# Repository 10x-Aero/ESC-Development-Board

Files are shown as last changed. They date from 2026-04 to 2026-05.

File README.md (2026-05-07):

https://github.com/user-attachments/assets/5f652ef7-dc9c-4700-bebd-08a81333550c

# ESC Development Board

A 6S AM32-compatible ESC built as a proof of concept for learning how to design an ESC from scratch. It gets a motor spinning — that's about the extent of what's guaranteed. Beyond that, expect rough edges.

The design is sloppy in places. If you spot schematic, layout, or component choices that actively work against basic ESC functionality, open an issue.

## Hardware

- **MCU:** STM32F051
- **Firmware:** AM32
- **Max cells:** 6S

<p align="center">
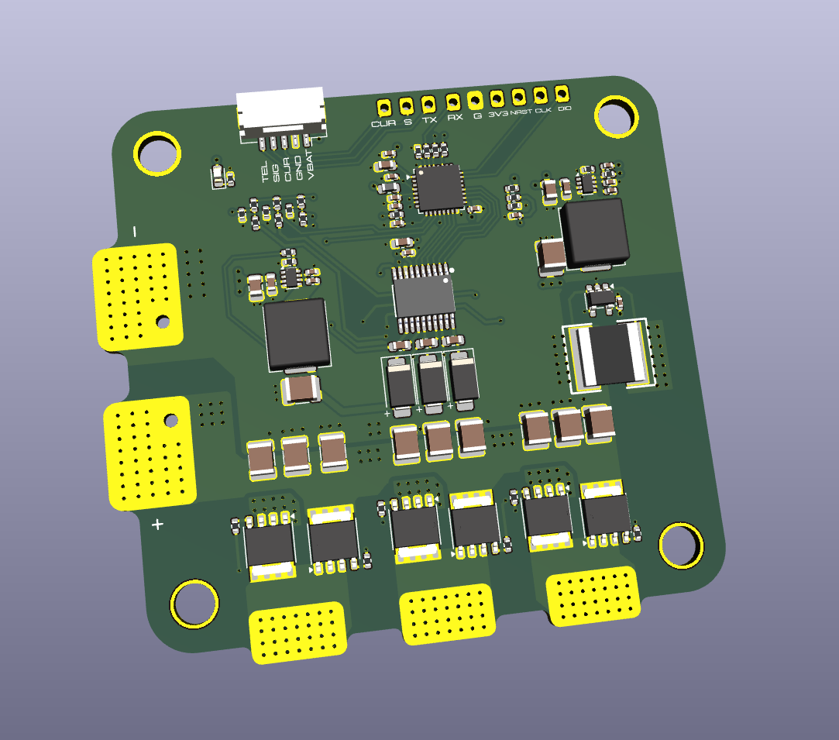
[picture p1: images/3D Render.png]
Front
  
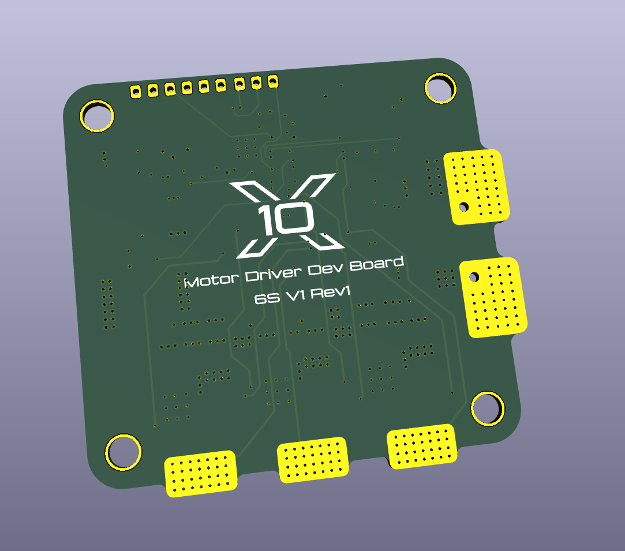
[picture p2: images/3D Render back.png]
Back
  
</p>

### Schematic

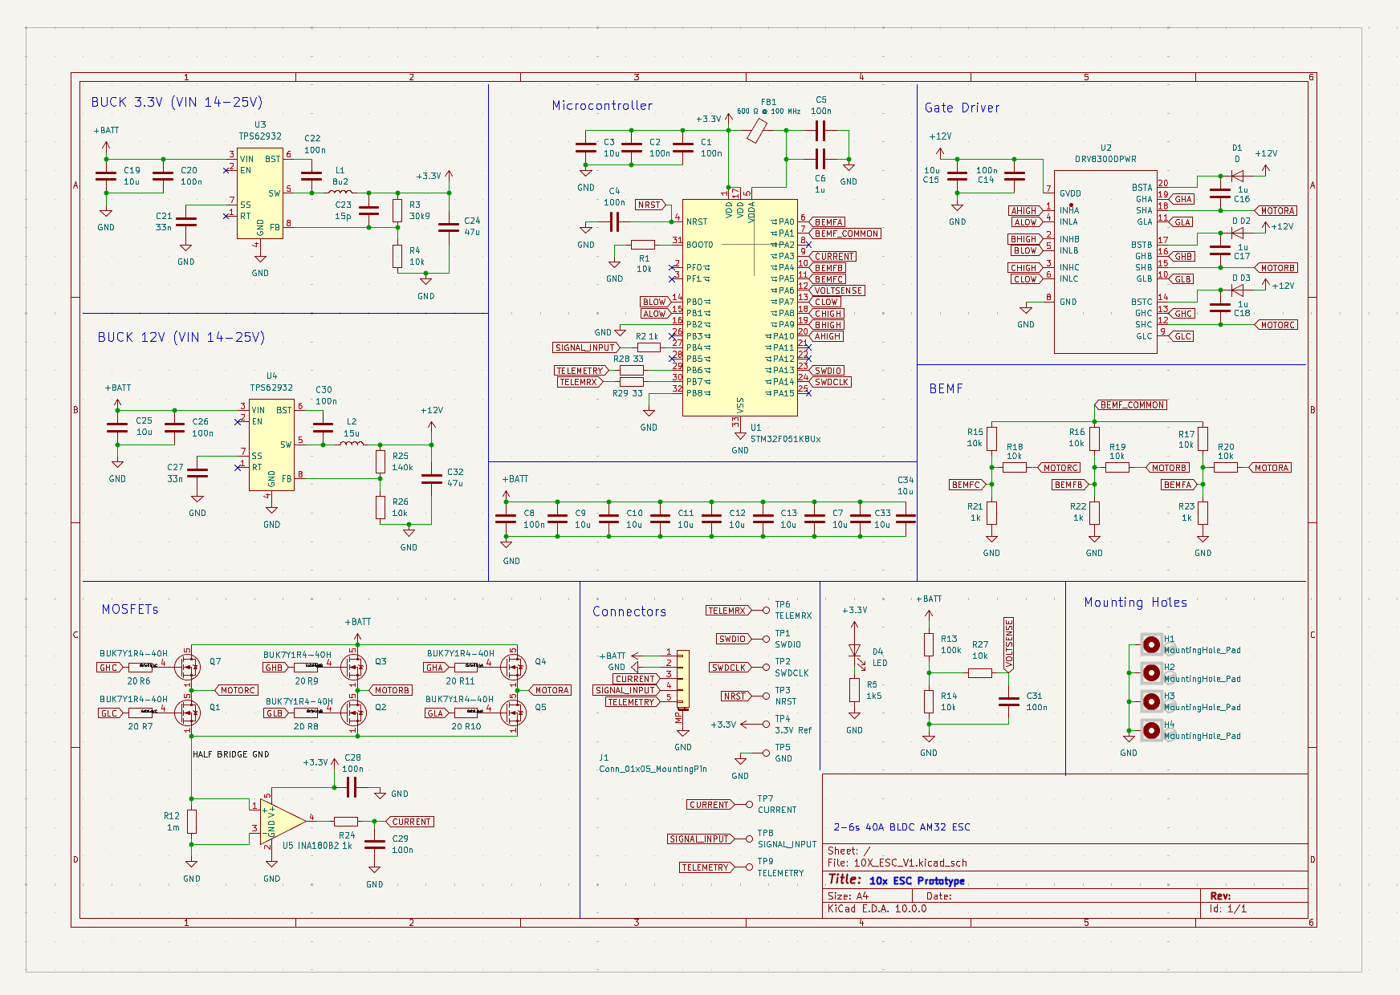
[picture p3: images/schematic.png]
Schematic


### PCB layers

<p align="center">
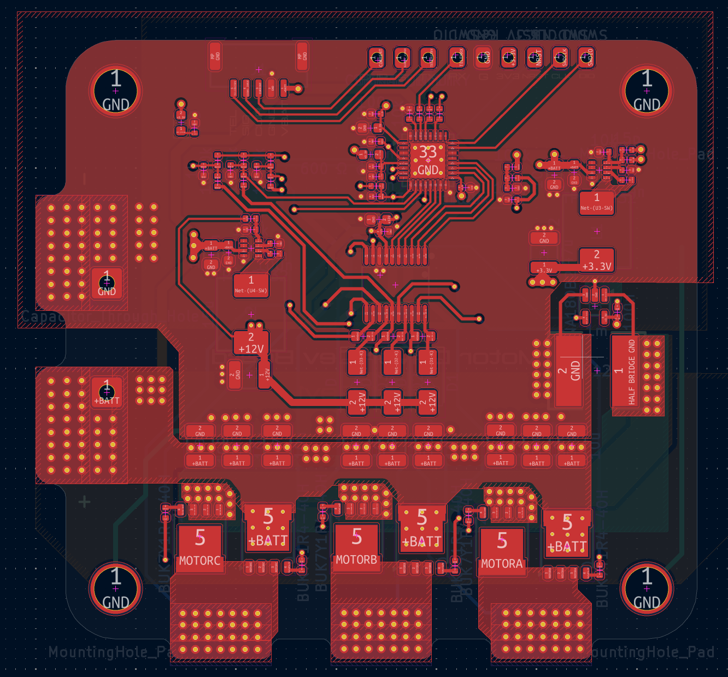
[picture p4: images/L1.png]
Layer 1 — Top
  
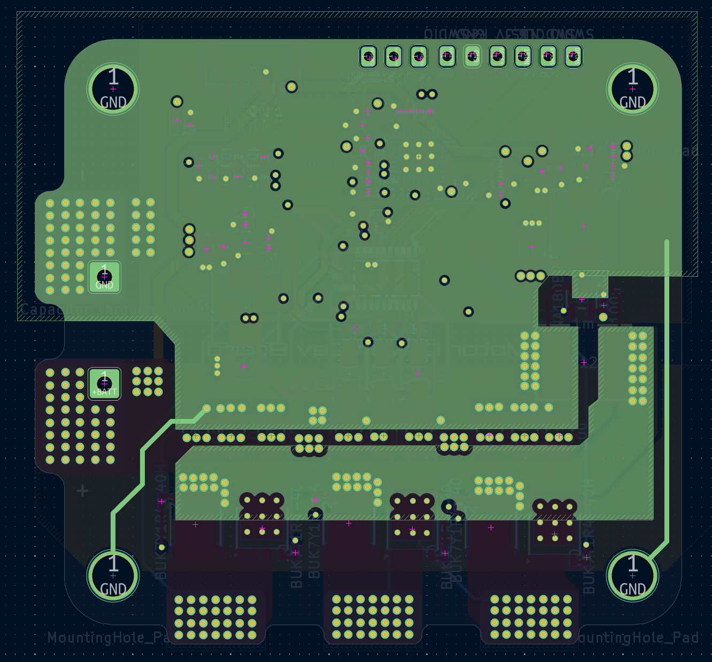
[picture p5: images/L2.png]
Layer 2
  
</p>
<p align="center">
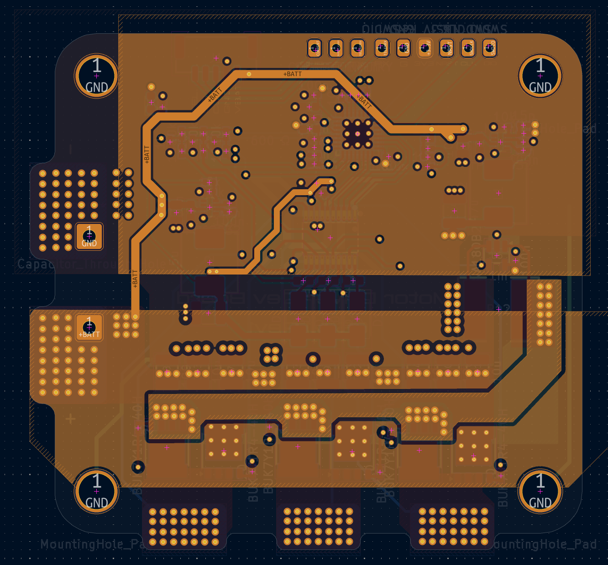
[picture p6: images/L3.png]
Layer 3
  
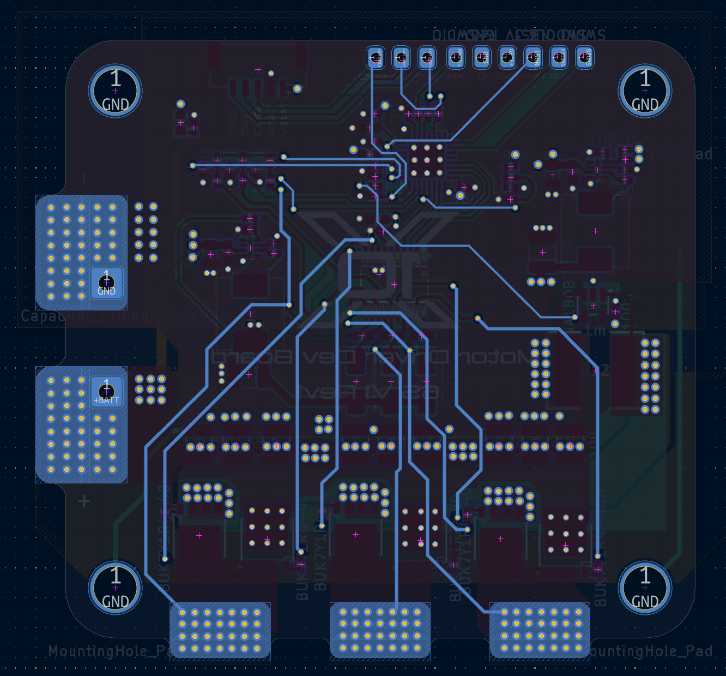
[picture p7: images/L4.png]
Layer 4 — Bottom
  
</p>

PCB

## Testing

### Setup

- **Motor:** AOS Supernova 3220 925KV
- **Battery:** 6S LiPo
- **Prop:** 7×7
- **Bulk cap:** 1000 µF
- **Measurement:** AC-coupled VBAT ripple, probed directly at the battery solder pads

### Throttle sequence

| t (s) | Action | Throttle | Duration |
| ----- | --- | --- | --- |
| 0.0 | Idle | — | 1.0 s |
| 1.0 | Ramp | 0 → 20%  | 1.5 s |
| 2.5 | Hold (capture) | 20% | 2.0 s |
| 4.5 | Ramp | 20 → 35% | 0.8 s |
| 5.3 | Hold (capture) | 35% | 2.0 s |
| 7.3 | Ramp | 35 → 50% | 0.8 s |
| 8.1 | Hold (capture) | 50% | 2.0 s |
| 10.1  | Ramp | 50 → 65% | 0.8 s |
| 10.9  | Hold (capture) | 65% | 2.0 s |
| 12.9  | Ramp | 65 → 80% | 0.8 s |
| 13.7  | Hold (capture) | 80% | 2.0 s |
| 15.7  | Ramp | 80 → 95% | 0.8 s |
| 16.5  | Hold (capture) | 95% | 2.0 s |
| 18.5  | Ramp down | 95 → 0%  | 1.5 s |
| 20.0  | End | — | — |

### Results

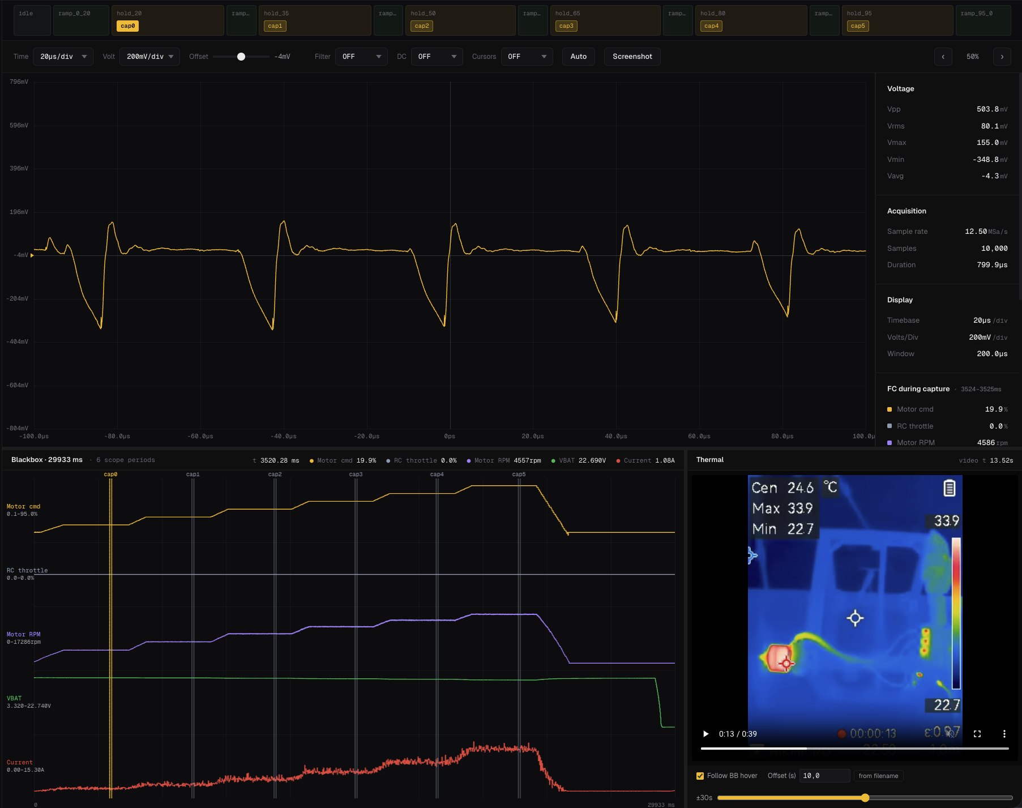
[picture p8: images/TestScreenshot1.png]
VBAT ripple — low throttle


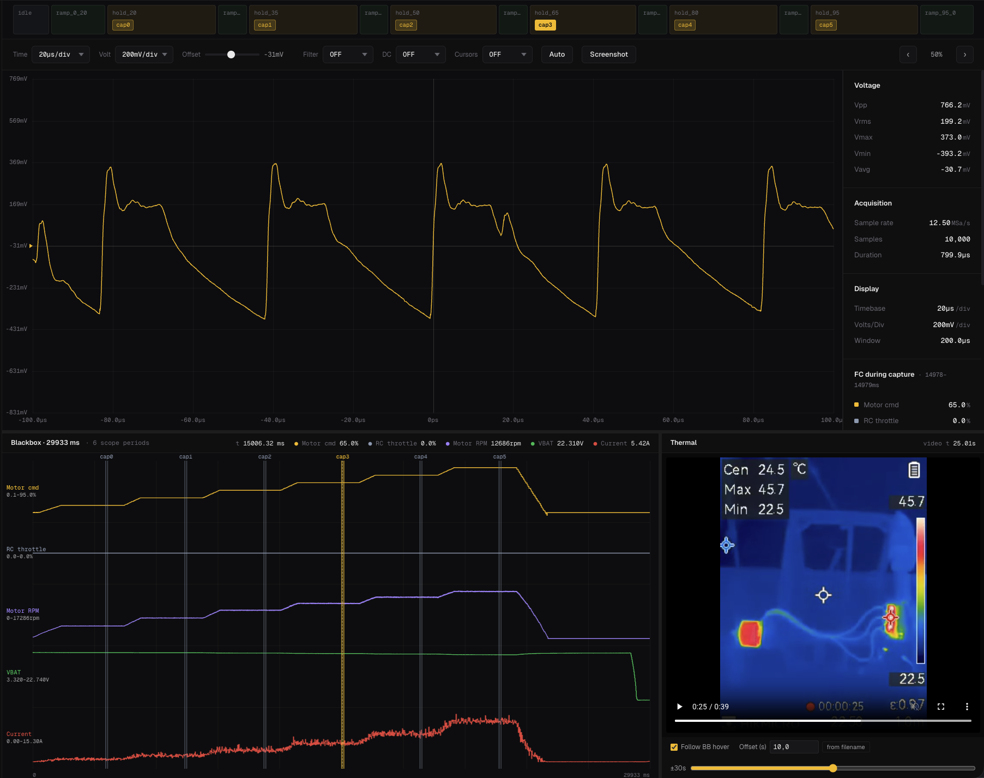
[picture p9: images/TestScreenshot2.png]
VBAT ripple — mid throttle


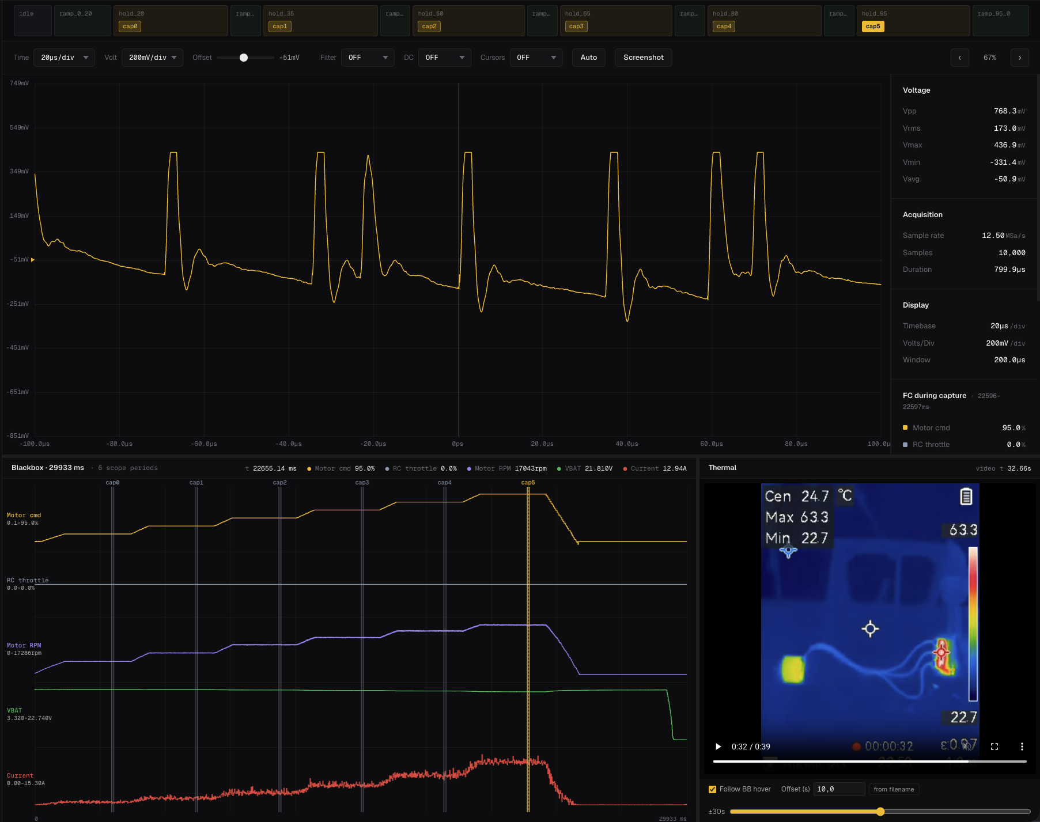
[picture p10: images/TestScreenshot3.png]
VBAT ripple — high throttle


https://github.com/user-attachments/assets/3ce99b9d-343a-43b4-ace9-065e4792fe87

## Known mistakes

- The DRV8300DPWR has internal bootstrap diodes, so the external bootstrap diodes on this design are redundant. Doesn't break anything — just unnecessary parts cost and board area.

## Flashing AM32 on a custom ESC

General workflow for getting AM32 running on any custom STM32-based ESC, not just this one. Two things to figure out for your own board: which AM32 target matches your pin layout, and how to physically flash it.

### Figuring out the pin config

AM32 organizes pin assignments in two layers:

- **Hardware groups** define the low-level pins — signal input, the six phase outputs (three high-side PWM + three low-side COM), BEMF feedback pins, and the comparator reference. Grouped per MCU family (`F0_A`, `F0_B`, etc.) and listed in the [AM32 Supported Hardware wiki](https://github.com/AlkaMotors/AM32-MultiRotor-ESC-firmware/wiki/List-of-Supported-Hardware).
- **Targets** sit on top of a hardware group and add ADC pins for voltage and current sensing, plus anything board-specific like LED pins. Target definitions live in `Inc/targets.h` in the [am32-firmware/AM32 repo](https://github.com/am32-firmware/AM32) as `#ifdef` blocks.

Compare your schematic against the hardware group table. If one matches your phase outputs, BEMF pins, and signal input exactly, use it and write a target that points to your ADC pins. If nothing matches, you'll need to define a new hardware group — that means editing the MCU-level source, not just a target header.

Match your signal input pin carefully. The bootloader `.hex` filename encodes which pin it expects (e.g. `..._PB4_V17.hex` expects the signal on PB4). Mismatches mean the ESC won't respond to the configurator.

### Flashing the bootloader

SWD only — the bootloader has to go on over ST-Link. Wire SWDIO, SWCLK, and GND from the ST-Link to the SWD pads on the ESC, and power the ESC from a LiPo.

1. Install [ST-LINK Utility](https://www.st.com/en/development-tools/stsw-link004.html).
2. Grab the correct bootloader from [am32.ca/downloads](https://am32.ca/downloads).
3. Flash the `.hex` to `0x08000000`.

### Flashing the firmware

Once the bootloader is on, the main firmware goes over the signal wire via FC passthrough — no more SWD needed.

1. Connect the ESC's signal and GND to a flight controller motor output, and plug the FC into your PC via USB.
2. Install the [AM32 Offline Configurator](https://github.com/am32-firmware/Offline-Configurator/releases).
3. Download the firmware `.hex` matching your target from the [AM32 releases](https://github.com/am32-firmware/AM32/releases).
4. Open the configurator, connect to the FC's serial port, and flash the `.hex`.

The FC needs to be running a DShot protocol (300 or 600) for passthrough to work, and the ESC needs battery power — USB alone won't boot it.

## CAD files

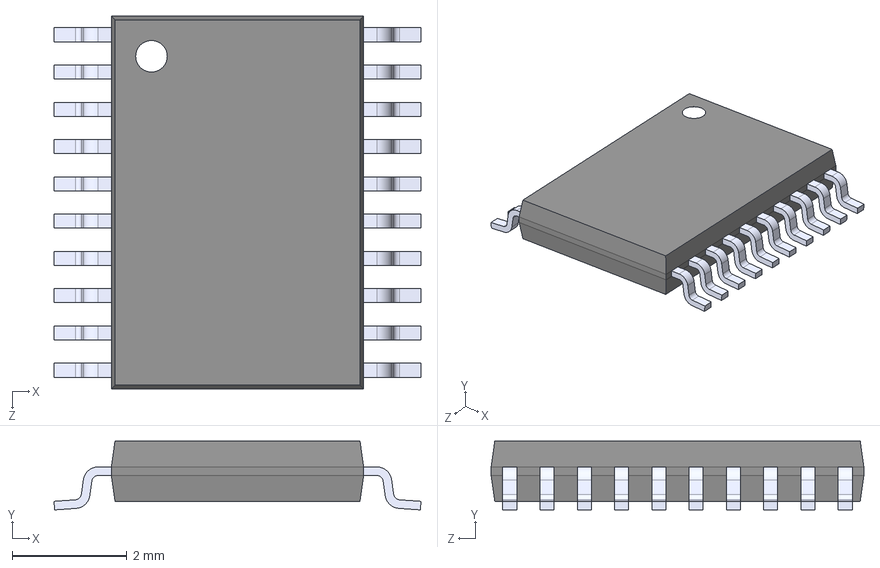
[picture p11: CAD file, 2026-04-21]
3D models/DRV8300DPWR.STEP
6.40 x 1.20 x 6.50 mm

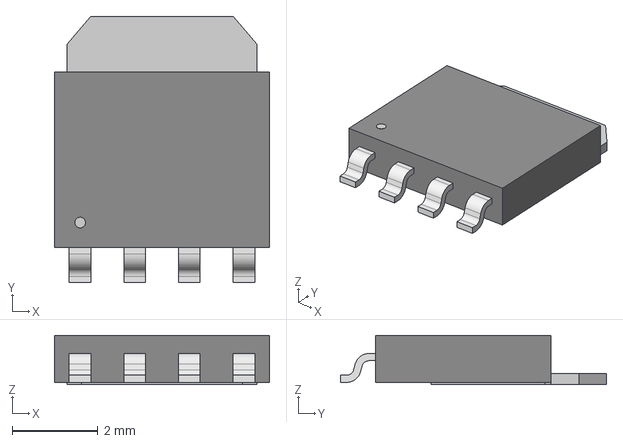
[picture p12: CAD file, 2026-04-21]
3D models/LFPAK56_SOT669_NEX.step
5.00 x 6.20 x 1.15 mm

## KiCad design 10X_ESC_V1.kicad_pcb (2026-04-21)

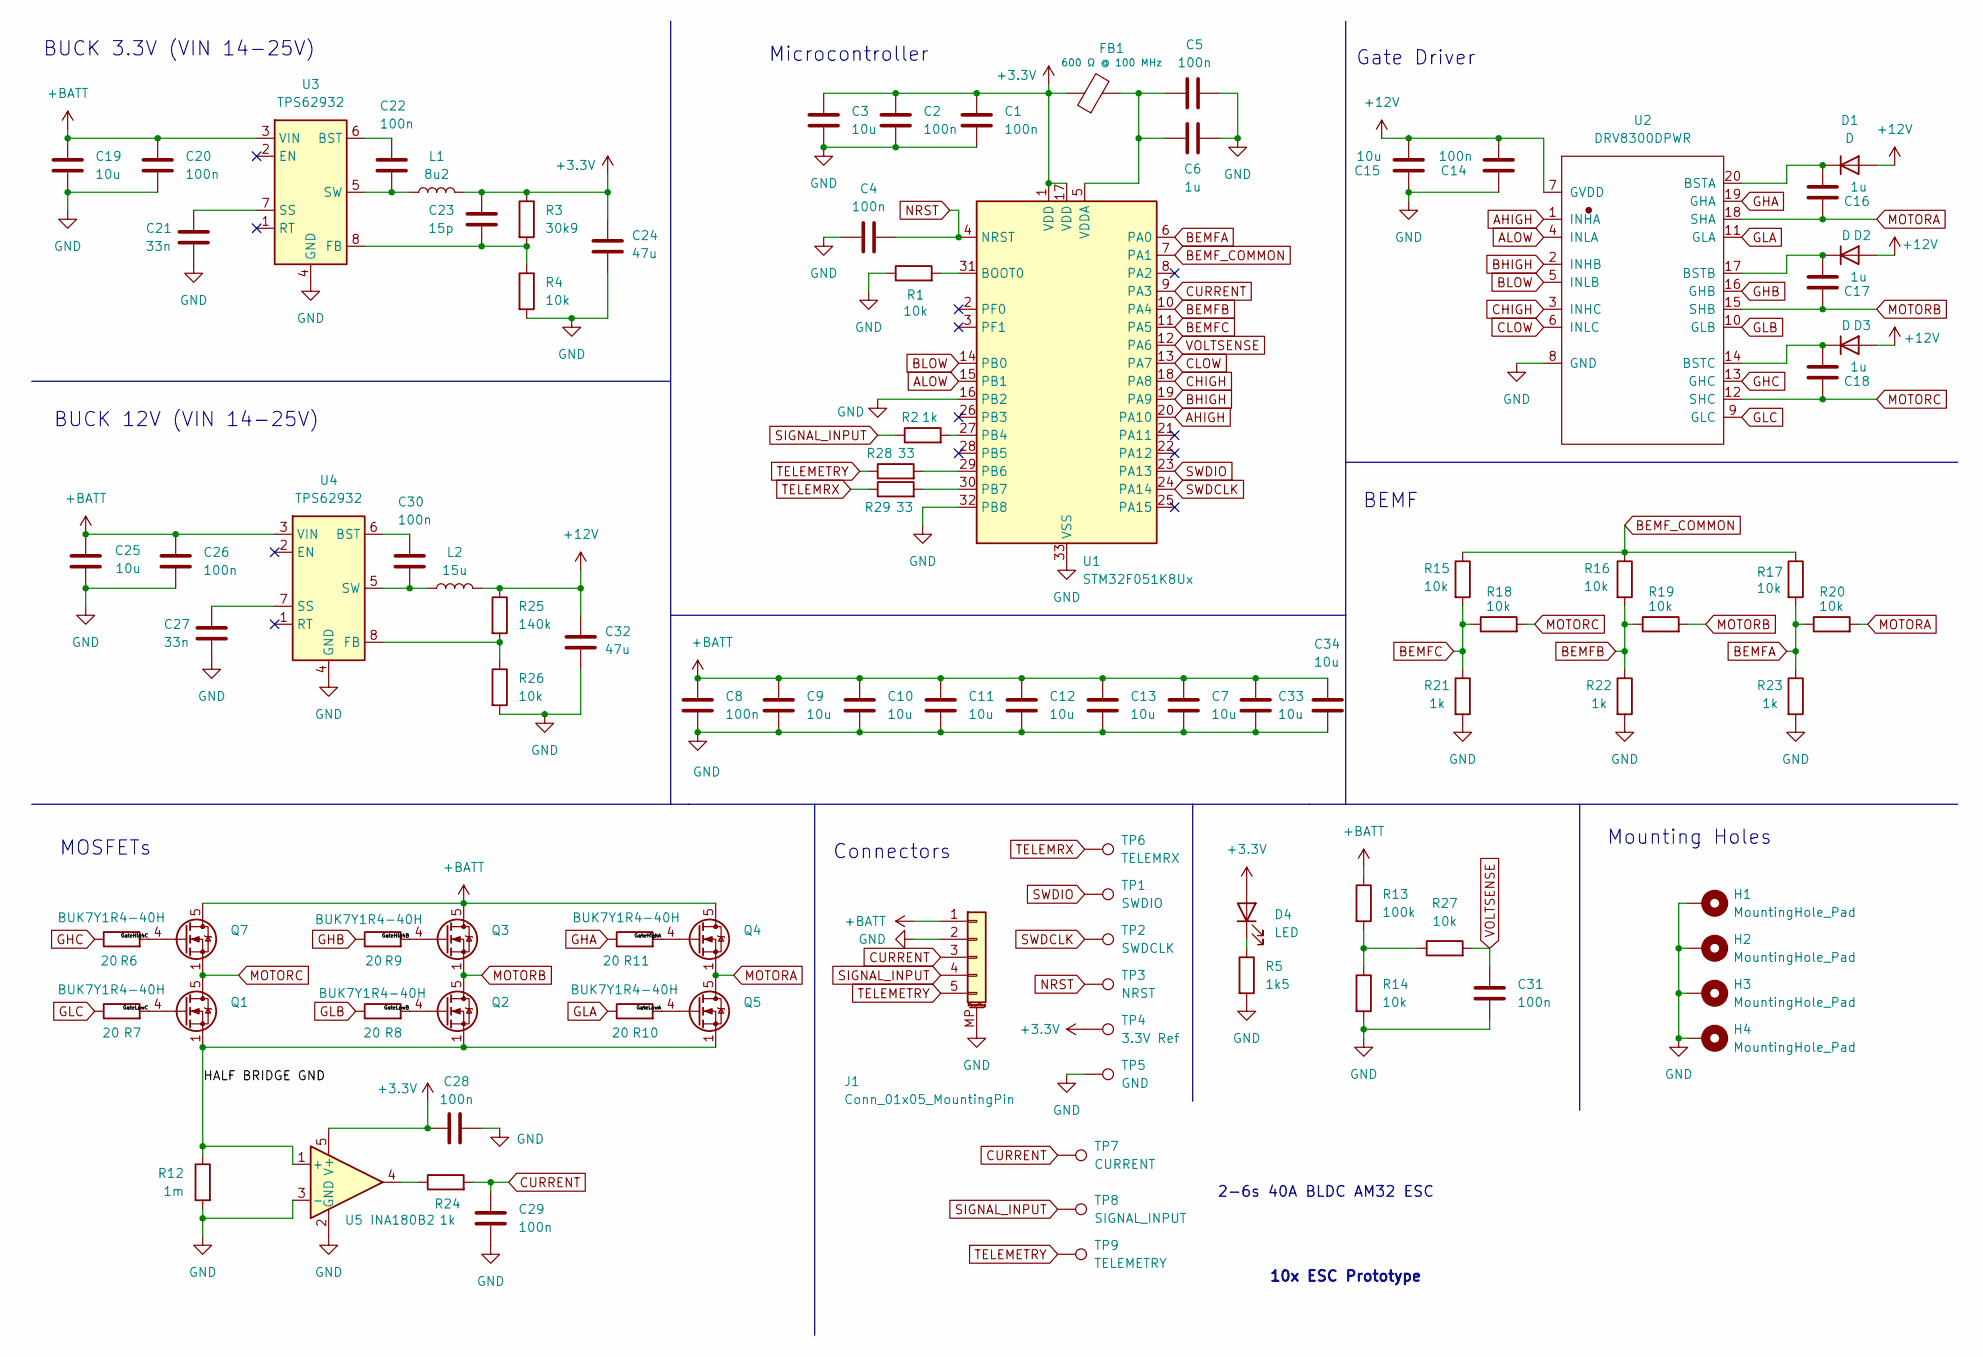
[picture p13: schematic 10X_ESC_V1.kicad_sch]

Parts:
C1, C2, C4, C5, C14, C22, C28, C29, C30, C31: 100n; C_0402_1005Metric; Manufacturer Part Number CA0522618; LCSC Part # C307331
C3, C15: 10u; C_0603_1608Metric; LCSC Part # C96446
C6: 1u; C_0402_1005Metric; LCSC Part # C52923
C7, C9, C10, C11, C12, C13, C33, C34: 10u; C_1210_3225Metric; LCSC Part # C53084452
C8: 100n; C_1210_3225Metric; LCSC Part # C2179722
C16, C17, C18: 1u; C_0603_1608Metric; LCSC Part # C15849
C19, C25: 10u; C_0805_2012Metric; LCSC Part # C440198
C20, C26: 100n; C_0603_1608Metric; LCSC Part # C14663
C21, C27: 33n; C_0402_1005Metric; LCSC Part # C106862
C23: 15p; C_0402_1005Metric; LCSC Part # C1548
C24, C32: 47u; C_1210_3225Metric; LCSC Part # C77101
D1, D2, D3: D; D_SMA; LCSC Part # C2480
D4: LED; LED_0603_1608Metric; LCSC Part # C111340
FB1: 600 Ω @ 100 MHz; L_0603_1608Metric; LCSC Part # C85833
H1, H2, H3, H4: MountingHole_Pad; Flightcontroller_MountingHolePad_M4
J1: Conn_01x05_MountingPin; JST_GH_SM05B-GHS-TB_1x05-1MP_P1.25mm_Horizontal; LCSC Part # C189896
L1: 8u2; L_KOHERelec_MDA7030; LCSC Part # C436550
L2: 15u; L_KOHERelec_MDA7030; LCSC Part # C2847486
Q1, Q2, Q3, Q4, Q5, Q7: BUK7Y1R4-40H; LFPAK56; LCSC Part # C6423721
R1, R4, R14, R15, R16, R17, R18, R19, R20, R26, R27: 10k; R_0402_1005Metric; LCSC Part # C25744
R2, R21, R22, R23, R24: 1k; R_0402_1005Metric; LCSC Part # C11702
R3: 30k9; R_0402_1005Metric; LCSC Part # C270615
R5: 1k5; R_0402_1005Metric; LCSC Part # C25867
R6, R7, R8, R9, R10, R11: 20; R_0402_1005Metric; LCSC Part # C25089
R12: 1m; R2725; LCSC Part # C469381
R13: 100k; R_0402_1005Metric; LCSC Part # C25741
R25: 140k; R_0402_1005Metric; LCSC Part # C114151
R28, R29: 33; R_0402_1005Metric; LCSC Part # C25105
TP1: SWDIO; Flightcontroller_Solder_Pad
TP2: SWDCLK; Flightcontroller_Solder_Pad
TP3: NRST; Flightcontroller_Solder_Pad
TP4: 3.3V Ref; Flightcontroller_Solder_Pad
TP5: GND; Flightcontroller_Solder_Pad
TP6: TELEMRX; Flightcontroller_Solder_Pad
TP7: CURRENT; Flightcontroller_Solder_Pad
TP8: SIGNAL_INPUT; Flightcontroller_Solder_Pad
TP9: TELEMETRY; Flightcontroller_Solder_Pad
U1: STM32F051K8Ux; QFN-32-1EP_5x5mm_P0.5mm_EP3.45x3.45mm; LCSC Part # C72339
U2: DRV8300DPWR; TSSOP-20_L6.5-W4.4-P0.65-LS6.4-BL; LCSC Part # C3036056
U3, U4: TPS62932; SOT-583-8; LCSC Part # C3032935
U5: INA180B2; SOT-23-5; LCSC Part # C2861539

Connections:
+3.3V: C1.1, C2.1, C3.1, C23.1, C24.1, C28.1, D4.2 (A), FB1.1, L1.2, R3.1, TP4.1, U1.1 (VDD), U1.17 (VDD), U5.5 (V+)
+12V: C14.2, C15.2, C32.1, D1.2 (A), D2.2 (A), D3.2 (A), L2.2, R25.1, U2.7 (GVDD)
+BATT: C7.1, C8.1, C9.1, C10.1, C11.1, C12.1, C13.1, C19.1, C20.1, C25.1, C26.1, C33.1, C34.1, J1.1, Q3.5 (D), Q4.5 (D), Q7.5 (D), R13.1, U3.3 (VIN), U4.3 (VIN)
/GateHighA: Q4.4 (G), R11.2
/GateHighB: Q3.4 (G), R9.2
/GateHighC: Q7.4 (G), R6.2
/GateLowA: Q5.4 (G), R10.2
/GateLowB: Q2.4 (G), R8.2
/GateLowC: Q1.4 (G), R7.2
/HALF BRIDGE GND: Q1.1 (S), Q1.2 (S), Q1.3 (S), Q2.1 (S), Q2.2 (S), Q2.3 (S), Q5.1 (S), Q5.2 (S), Q5.3 (S), R12.1, U5.1 (+)
AHIGH: U1.20 (PA10), U2.1 (INHA)
ALOW: U1.15 (PB1), U2.4 (INLA)
BEMFA: R17.2, R20.1, R23.1, U1.6 (PA0)
BEMFB: R16.2, R19.1, R22.1, U1.10 (PA4)
BEMFC: R15.2, R18.1, R21.1, U1.11 (PA5)
BEMF_COMMON: R15.1, R16.1, R17.1, U1.7 (PA1)
BHIGH: U1.19 (PA9), U2.2 (INHB)
BLOW: U1.14 (PB0), U2.5 (INLB)
CHIGH: U1.18 (PA8), U2.3 (INHC)
CLOW: U1.13 (PA7), U2.6 (INLC)
CURRENT: C29.1, J1.3, R24.2, TP7.1, U1.9 (PA3)
GHA: R11.1, U2.19 (GHA)
GHB: R9.1, U2.16 (GHB)
GHC: R6.1, U2.13 (GHC)
GLA: R10.1, U2.11 (GLA)
GLB: R8.1, U2.10 (GLB)
GLC: R7.1, U2.9 (GLC)
GND: C1.2, C2.2, C3.2, C4.1, C5.2, C6.2, C7.2, C8.2, C9.2, C10.2, C11.2, C12.2, C13.2, C14.1, C15.1, C19.2, C20.2, C21.2, C24.2, C25.2, C26.2, C27.2, C28.2, C29.2, C31.2, C32.2, C33.2, C34.2, H1.1, H2.1, H3.1, H4.1, J1.2, J1.MP (MountPin), R1.1, R4.2, R5.2, R12.2, R14.2, R21.2, R22.2, R23.2, R26.2, TP5.1, U1.16 (PB2), U1.32 (PB8), U1.33 (VSS), U2.8 (GND), U3.4 (GND), U4.4 (GND), U5.2 (GND), U5.3 (-)
MOTORA: C16.1, Q4.1 (S), Q4.2 (S), Q4.3 (S), Q5.5 (D), R20.2, U2.18 (SHA)
MOTORB: C17.1, Q2.5 (D), Q3.1 (S), Q3.2 (S), Q3.3 (S), R19.2, U2.15 (SHB)
MOTORC: C18.1, Q1.5 (D), Q7.1 (S), Q7.2 (S), Q7.3 (S), R18.2, U2.12 (SHC)
NRST: C4.2, TP3.1, U1.4 (NRST)
unnamed: C16.2, D1.1 (K), U2.20 (BSTA)
unnamed: C17.2, D2.1 (K), U2.17 (BSTB)
unnamed: C18.2, D3.1 (K), U2.14 (BSTC)
unnamed: D4.1 (K), R5.1
unnamed: R13.2, R14.1, R27.1
unnamed: R24.1, U5.4
unnamed: R1.2, U1.31 (BOOT0)
unnamed: R2.2, U1.27 (PB4)
unnamed: R28.2, U1.29 (PB6)
unnamed: R29.2, U1.30 (PB7)
unnamed: C5.1, C6.1, FB1.2, U1.5 (VDDA)
unnamed: C22.1, U3.6 (BST)
unnamed: C23.2, R3.2, R4.1, U3.8 (FB)
unnamed: C21.1, U3.7 (SS)
unnamed: C22.2, L1.1, U3.5 (SW)
unnamed: C30.1, U4.6 (BST)
unnamed: R25.2, R26.1, U4.8 (FB)
unnamed: C27.1, U4.7 (SS)
unnamed: C30.2, L2.1, U4.5 (SW)
SIGNAL_INPUT: J1.4, R2.1, TP8.1
SWDCLK: TP2.1, U1.24 (PA14)
SWDIO: TP1.1, U1.23 (PA13)
TELEMETRY: J1.5, R28.1, TP9.1
TELEMRX: R29.1, TP6.1
VOLTSENSE: C31.1, R27.2, U1.12 (PA6)

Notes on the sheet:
2-6s 40A BLDC AM32 ESC
BEMF
MOSFETs
Gate Driver
BUCK 3.3V (VIN 14-25V)
Mounting Holes
10x ESC Prototype
BUCK 12V (VIN 14-25V)
Microcontroller
Connectors

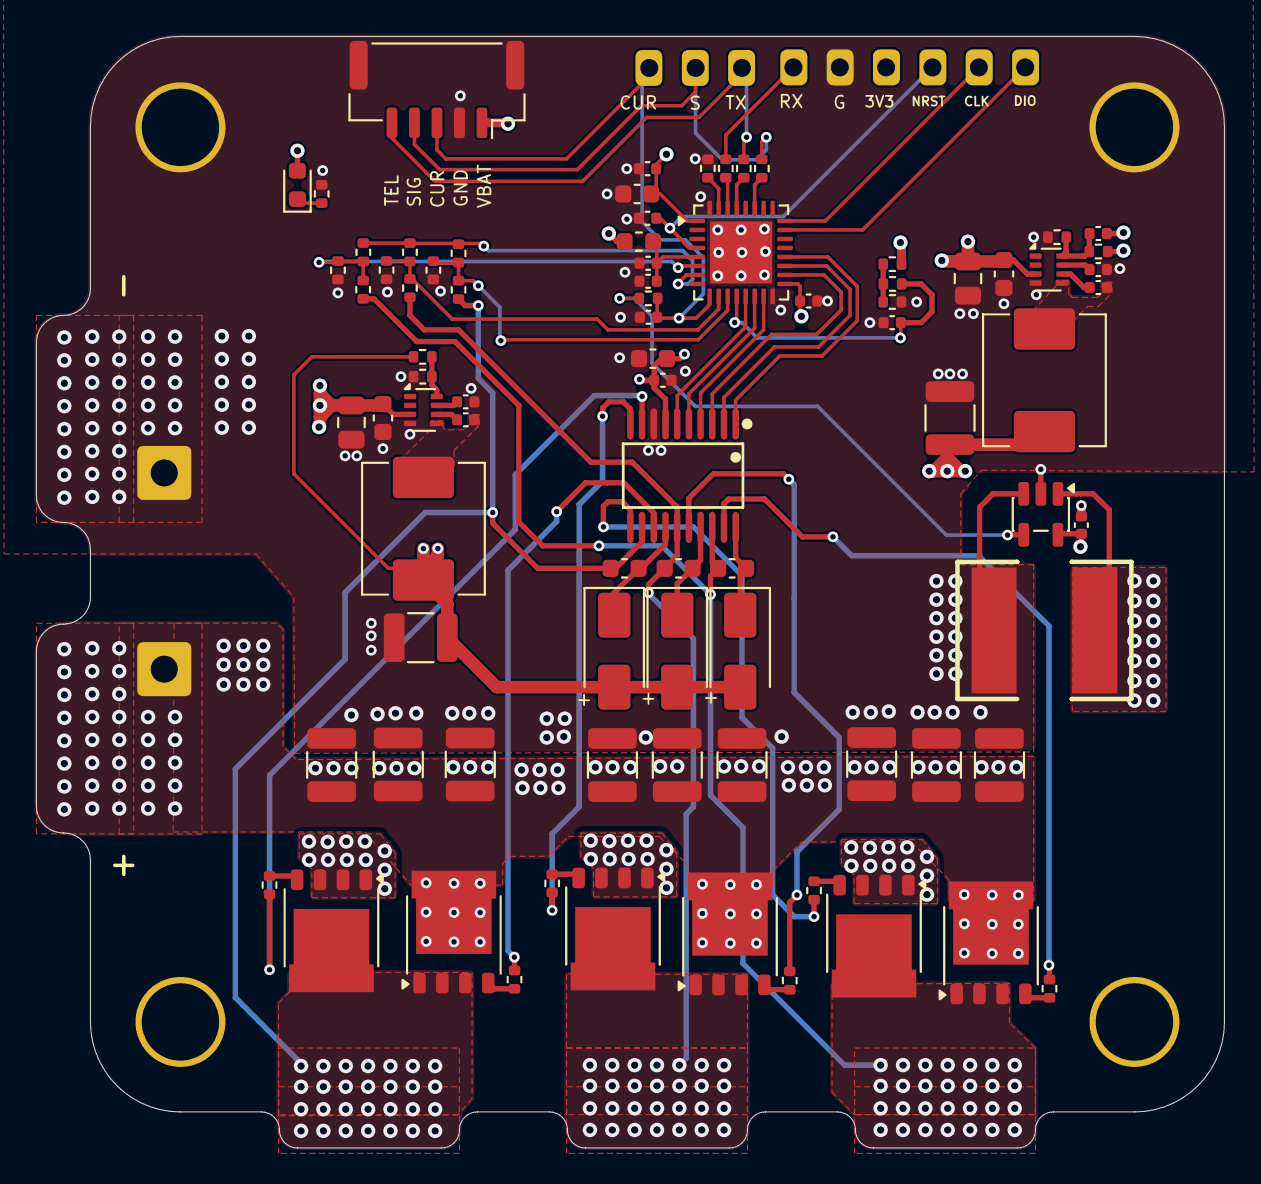
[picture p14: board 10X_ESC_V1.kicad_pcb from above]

Board: 4 copper layers, 66.0 x 61.8 mm, 95 parts (0 on the bottom side), 57 nets.
